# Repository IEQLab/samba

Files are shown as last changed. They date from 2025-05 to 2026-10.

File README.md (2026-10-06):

# SAMBA IEQ Monitoring System

This repository contains the firmware for SAMBA v2, a low-cost indoor environmental quality (IEQ) monitor developed by the [IEQ Lab](https://www.sydney.edu.au/architecture/our-research/research-labs-and-facilities/indoor-environmental-quality-lab.html) at The University of Sydney. SAMBA runs on [ESPHome](https://esphome.io), an open-source firmware framework for ESP32 microcontrollers. The minimum supported version of ESPHome is **2026.9.1**.

### Configuration

ESPHome devices are configured using [YAML](https://yaml.org). This repository is structured so that each sensor or function has its own config file in `config/`, which are imported as [packages](https://esphome.io/components/packages/) by the main [`samba.yaml`](https://github.com/IEQLab/samba/blob/main/samba.yaml).

```
├── samba.yaml              # main config
├── config/
|   ├── adc.yaml            # analog-to-digital converter
|   ├── airspeed.yaml       # anemometers
|   ├── calibration.yaml    # calibration coefficients
|   ├── co2.yaml            # CO2 sensor
|   ├── diagnostics.yaml    # device diagnostics
|   ├── esp32.yaml          # ESP32 board and framework
|   ├── fileserver.yaml     # SD file server for SAMBA Home
|   ├── globals.yaml        # global variables
|   ├── homeassistant.yaml  # Home Assistant API
|   ├── illuminance.yaml    # illuminance sensor
|   ├── influx.yaml         # InfluxDB connection
|   ├── led.yaml            # status LED
|   ├── ota.yaml            # over-the-air updates
|   ├── pm25.yaml           # PM2.5 sensor
|   ├── rtc.yaml            # real-time clock
|   ├── sample.yaml         # sampling loop
|   ├── sd.yaml             # SD card logging
|   ├── spl.yaml            # sound pressure level
|   ├── substitutions.yaml  # secrets and substitutions
|   ├── tags.yaml           # InfluxDB location tags
|   ├── tair.yaml           # air temperature and RH
|   ├── tglobe.yaml         # globe temperature
|   ├── tvoc.yaml           # TVOC and NOx sensor
|   └── wifi.yaml           # wireless networking
├── components/             # custom ESPHome components
|   ├── influxdb/           # InfluxDB v2 HTTP upload
|   ├── sd_file_server/     # read-only HTTP access to the SD log
|   ├── sd_spi_card/        # SPI SD card read/write
|   ├── senseair_i2c/       # K30/K33 CO2 over I2C
|   ├── sgp4x/              # ESPHome's SGP4x, with setup retries
|   └── sound_level_meter/  # I2S audio DSP for SPL
├── firmware/               # compiled binaries for OTA
└── pcb/                    # hardware design files (Altium)
```

The `components/` directory contains six [external components](https://esphome.io/components/external_components.html) that extend ESPHome:

1. `sound_level_meter` — audio DSP for sound pressure level (LAeq, LA90, LA10)
2. `senseair_i2c` — I2C driver for the [K30 CO2 sensor](https://www.co2meter.com/en-au/products/k-30-co2-sensor-module)
3. `influxdb` — HTTP upload to an InfluxDB v2 bucket
4. `sd_spi_card` — FAT32 SD card logging via SPI
5. `sd_file_server` — read-only HTTP service over the SD card log for the SAMBA Home app
6. `sgp4x` — ESPHome's own SGP4x driver, overridden locally so a transaction lost during setup is
   retried instead of disabling VOC and NOx until the next reboot

### Sensors

| Parameter | Sensor | Config | Component |
|:---:|:---:|:---:|:---:|
| Temperature / RH | [Sensirion SHT40](https://sensirion.com/products/catalog/SHT40/) | [tair.yaml](https://github.com/IEQLab/samba/blob/main/config/tair.yaml) | [sht4x](https://esphome.io/components/sensor/sht4x.html) |
| Globe Temperature | [NTC Thermistor](https://www.murata.com/en-us/products/productdetail?partno=NXRT15XH103FA1B040) | [tglobe.yaml](https://github.com/IEQLab/samba/blob/main/config/tglobe.yaml) | [ntc](https://esphome.io/components/sensor/ntc.html) |
| Air Speed | [Thermal Anemometer](https://moderndevice.com/products/wind-sensor) | [airspeed.yaml](https://github.com/IEQLab/samba/blob/main/config/airspeed.yaml) | [ads1115](https://esphome.io/components/sensor/ads1115.html) |
| CO2 | [CO2Meter K30](https://www.co2meter.com/en-au/products/k-30-co2-sensor-module) | [co2.yaml](https://github.com/IEQLab/samba/blob/main/config/co2.yaml) | [senseair_i2c](https://github.com/IEQLab/samba/tree/main/components/senseair_i2c) |
| PM2.5 | [Plantower PMS5003T](https://www.plantower.com/en/products_33/74.html) | [pm25.yaml](https://github.com/IEQLab/samba/blob/main/config/pm25.yaml) | [pmsx003](https://esphome.io/components/sensor/pmsx003.html) |
| VOC / NOx Index | [Sensirion SGP41](https://sensirion.com/products/catalog/SGP41/) | [tvoc.yaml](https://github.com/IEQLab/samba/blob/main/config/tvoc.yaml) | [sgp4x](https://esphome.io/components/sensor/sgp4x.html) |
| Illuminance | [TI OPT3001](https://www.ti.com/product/OPT3001) | [illuminance.yaml](https://github.com/IEQLab/samba/blob/main/config/illuminance.yaml) | [opt3001](https://esphome.io/components/sensor/opt3001.html) |
| Sound Pressure Level | [ICS-43434 Microphone](https://invensense.tdk.com/products/ics-43434/) | [spl.yaml](https://github.com/IEQLab/samba/blob/main/config/spl.yaml) | [sound_level_meter](https://github.com/stas-sl/esphome-sound-level-meter) |

Most sensors are natively supported by ESPHome. The CO2 sensor and sound pressure level measurement use custom external components in `components/`.

### Anemometer Tips

The remote board has two thermal anemometer tips, one on each face. The firmware numbers them the other way round from the [schematic](https://github.com/IEQLab/samba/blob/main/pcb/remote/schematics.pdf), so identify a tip by the face it is on:

| Face | Tip | Schematic sheet | Firmware |
|:----:|:---:|:---:|:---:|
| RJ45 connector | R9 | Airspeed 1 | `as2` (ADS1115 `A1`) |
| Opposite face | R27 | Airspeed 2 | `as1` (ADS1115 `A0`) |

The published `Air Speed` is the larger of the two, or the one still reporting if the other has dropped out.

### Sampling

SAMBA continuously measures environmental parameters, applies quality filters and a moving median, then publishes a summary every **5 minutes**. The routine is:

1. Each sensor measures at its own frequency (see table below).
2. Raw readings pass through [filters](https://esphome.io/components/sensor/index.html#sensor-filters) — NaN rejection, clamping, moving median — and calibration functions.
3. Every 5 minutes, a [cron task](https://esphome.io/components/time/index.html) on the RTC triggers the `sensor_sample` [script](https://esphome.io/guides/automations.html#script-component).
4. The script updates all [template sensors](https://esphome.io/components/sensor/template.html), then publishes to Home Assistant, InfluxDB, and/or the SD card. The LED flashes white with each upload.
5. Publishing is skipped during the first 2 minutes after boot (sensor warm-up).

| Measure | Frequency | Filters |
|:---:|:---:|:---:|
| Air Temperature | 30s | clamp; moving median; linear calibration |
| Relative Humidity | 30s | clamp; moving median; linear calibration |
| Globe Temperature | 23s | clamp; moving median; linear calibration |
| Air Speed | 2.3s | clamp; moving median; exponential calibration with air temperature |
| CO2 | 27s | filter; clamp; moving median; linear calibration; clamp |
| PM2.5 | ~1s | clamp; moving median |
| VOC Index | 30s | moving median |
| NOx Index | 30s | moving median |
| Illuminance | 20s | clamp; moving median; linear calibration; clamp |
| Sound Pressure Level | 125ms | sos (mic EQ, A-weighting); sliding 5min window of 125ms levels, sent each minute: energy average (LAeq), 0.1dB histogram quantiles (LA90, LA10) |

### Data

Published measurements are sent every 5 minutes to one or more of the following backends:

**[Home Assistant](https://www.home-assistant.io)** — An open-source home automation platform. Easy to use but requires additional hardware (e.g. Raspberry Pi) and some configuration to retain raw data beyond 10 days. Best suited for projects that also collect other measurements (e.g. energy, window/door state). Communication uses the native ESPHome [API component](https://esphome.io/components/api.html).

**[InfluxDB](https://www.influxdata.com/products/influxdb-overview/)** — An open-source time series database optimised for IoT. Can be self-hosted or used via InfluxData's cloud service. Requires an active internet connection. Best suited for field deployments of multiple SAMBAs. Communication uses the custom `influxdb` component with building, level, and zone IDs as tags (set over the native API, see [`config/tags.yaml`](https://github.com/IEQLab/samba/blob/main/config/tags.yaml)). See the [InfluxDB key concepts](https://docs.influxdata.com/influxdb/v1/concepts/key_concepts/) for background.

**SD Card** — Local CSV logging via the `sd_spi_card` component. Files are named using the device MAC address and UTC timestamp. No network connection required.

### Status LED

A single RGB LED on the board reports device state. One rule covers the whole scheme:
**colour identifies the subsystem, and pulsing versus solid identifies severity.** A slow
pulse is a warning the device expects to recover from on its own; a steady light means the fault
is sustained. Only the ADS1115 and K30 escalate to a restart, and only after an hour of uptime.
Brightness is deliberately low throughout so a rack of units is not distracting in an occupied
office.

For a bedroom or any space that should stay dark, turn off the *Status LED* switch (native API,
persists across reboots and updates). Every indication below is then suppressed, including the
boot flash, the sample heartbeat and the fault colours; faults are still logged and still
restart the unit as described. *Identify SAMBA* still blinks the LED, since it is only ever
pressed on purpose.

| LED | Meaning | What to do |
|-----|---|---|
| Green, flashing | Booting | Nothing — clears after startup |
| White, brief flash | 5-minute sample taken and uploaded | Nothing — this is the healthy heartbeat |
| Off | Running normally | Nothing |
| Amber, pulsing | Globe temperature / air speed unresponsive ~3 min | Watch — often transient |
| Amber, solid | Same, ~5 min. Restarts once the fault has covered 35% of the last hour (about 25 min continuous) | Check the RJ45 cable to the remote board, then reseat both ends |
| Blue, pulsing | CO2 (K30) failed 3 consecutive reads | Watch — usually self-recovers |
| Blue, solid | CO2 failed 4 or more; restarts once it has failed 67% of the last hour (about 65 min of near-total failure) | Check the K30; a persistent fault is often board-specific rather than the sensor |
| Magenta, pulsing | VOC / NOx (SGP4x) failed 4 consecutive reads | Watch — usually self-recovers |
| Magenta, solid | VOC / NOx failed 6 or more. Never restarts: the sensor keeps retrying itself, and a reboot would discard its month-long baseline | Check the sensor |

The LED is applied from a single 10-second poll of the error counters rather than from each
sensor's error handler, so it survives the sample heartbeat and returns to off within about ten
seconds of the sensor recovering. If two subsystems are in trouble at once, the more severe one
shows, and the ADS1115 wins a tie.

**A lit LED does not mean the device has stopped working.** A failed sensor is reported as
`nan` and left out of the upload, while every other measurement continues to be sampled and
sent. Restarts are rate-limited to at most one per hour precisely so that one dead sensor
cannot take the whole unit off the air.

Every sensor drops out the same way: each stamps the time of its last successful read, and a
measurand goes `nan` once that stamp is more than 5.5 minutes old — one sample interval plus
margin. A single failed read never costs a reading, because the sensors poll far faster than
they are sampled; it takes eleven consecutive failures for temperature, humidity or illuminance,
12 for CO2, 14 for globe temperature and about 140 for air speed. What this does *not* catch is
a sensor that keeps answering with a stuck value.

Amber is the one worth attention in the field: the remote board connects over an RJ45 lead,
and a marginal cable is the most common cause of it.

### Modifying Firmware

Users are free to modify the SAMBA firmware to suit their needs. We recommend familiarity with ESPHome and microcontroller programming before doing so. To get started:

1. Copy `secrets.yaml.example` to [`secrets.yaml`](https://esphome.io/guides/yaml.html#secrets-and-the-secrets-yaml-file) and set your InfluxDB server.
2. Modify the relevant `.yaml` files in `config/`.
3. Compile and upload via USB-C with `esphome run samba.yaml`, or wirelessly with `esphome run samba.yaml --device <IP_ADDRESS>`.

Calibration coefficients are stored as persistent [global variables](https://github.com/IEQLab/samba/blob/main/config/globals.yaml) and exposed as number entities over the native API (`config/calibration.yaml`), so they are set on the device rather than compiled in.

The user is responsible for managing any device running modified firmware.

### OTA Updates

SAMBA devices check for firmware updates every Monday at 04:00 UTC by comparing against [`firmware/manifest_v2.json`](https://github.com/IEQLab/samba/blob/main/firmware/manifest_v2.json). If a new version is available, the update is applied automatically after a random delay of up to 10 minutes to avoid fleet-wide simultaneous downloads. Units still on 1.x read [`firmware/manifest.json`](https://github.com/IEQLab/samba/blob/main/firmware/manifest.json) and never update to 2.x on their own; they move to 2.0 only when the IEQ Lab reflashes them. Automatic updates can be disabled with the *Automatic Updates* switch (see [Deployment](#deployment)).

### Deployment

SAMBA devices are shipped pre-calibrated, with their location tags (building, level, zone) and calibration coefficients already set by the IEQ Lab. Follow these steps to connect a new SAMBA to your network and start sampling:

1. **Power on** the SAMBA. The status LED blinks green while it boots. This firmware has no separate setup colour, so a unit still waiting for a network looks the same as one that is sampling.
2. **Connect to the hotspot.** Using a phone or laptop, join the SAMBA's own open WiFi network — it is named after the device, `samba-xxxxxx`, where `xxxxxx` is the last three bytes of its MAC address — and open the [captive portal](https://esphome.io/components/captive_portal.html) at [http://192.168.4.1](http://192.168.4.1). There is no password on the hotspot.
3. **Enter WiFi credentials.** Select the target 2.4 GHz network from the list and enter the password. The SAMBA will connect and begin sampling automatically. The LED will blink green during the warm-up period and then turn off once it enters the normal sampling routine.

**Switch it on in the room it will monitor.** The VOC sensor's index is relative: it learns a baseline from the air it sees in its first 45 minutes and then holds that baseline for about a month, so the first hour sets the scale every later TVOC reading is reported against. Boot the unit in its final position under normal conditions — not on a bench in another room, and not somewhere unusually clean or unusually solvent-heavy. If a unit's first hour was unrepresentative, power-cycling it within three hours discards the baseline and it learns again from scratch; after three hours only a firmware update clears it. This also means TVOC may step to a new baseline after an automatic update. Nothing else in the unit depends on where it is first switched on.

The location tags, the *InfluxDB Upload* / *SD Card Write* / *Automatic Updates* switches and the calibration coefficients are exposed over the [ESPHome native API](https://esphome.io/components/api.html), so they can be viewed and changed from [Home Assistant](https://www.home-assistant.io/integrations/esphome/) or with the IEQ Lab's `samba` laptop client from [samba_calibration](https://github.com/IEQLab/samba_calibration) (its *Identify SAMBA* button blinks the LED to pick one unit out of a batch). If you need a SAMBA recalibrated or re-tagged, please reach out — see [Project Maintenance](#project-maintenance) below.

The API is [encrypted](https://esphome.io/components/api.html#configuration-variables) with a key that is set on the device by the IEQ Lab during deployment rather than compiled into the firmware, so the published binaries carry no key; until one is set, the device accepts unencrypted connections so it can be provisioned. The same is true of the InfluxDB token and the OTA password (see `config/influx.yaml` and `config/ota.yaml`): each is stored on the device, survives updates, and the device only ever reports a fingerprint of it (*InfluxDB Token*, *OTA Password*) together with the result of its last upload (*InfluxDB Status*). The published firmware has no compiled-in fallbacks: a unit that has not been provisioned does not upload to InfluxDB and takes OTA updates without a password, so provision it before it leaves a network you trust. To upload to your own InfluxDB instead, set `token:` in `config/influx.yaml` in your build; a provisioned token still takes precedence. A unit going into a home gets a fourth credential, a pairing password that turns on a read-only HTTP service over the SD card log for the SAMBA Home app (see `config/fileserver.yaml` and [docs/home-sync.md](docs/home-sync.md)); without one the service is off and the unit behaves exactly as a building unit.

### Project Maintenance

This is an active project to build an open research platform for healthy, high-performance buildings. If you're interested in using SAMBA in your project or contributing to its development, start a [Github discussion](https://github.com/IEQLab/samba/discussions) or email Tom.

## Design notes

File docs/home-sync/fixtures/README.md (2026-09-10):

# Home sync conformance fixtures

These files are the shared test input for everything that reads a SAMBA SD log: `SambaCore` on
iOS, the Android port, and the firmware bench test. The wire contract itself is section 2 of
[../../home-sync.md](../../home-sync.md); this directory is that contract as bytes, so a port is
written against files rather than against someone else's source.

A parser conforms when, for each log file, it produces exactly the rows in `expected/`, and when
it handles every case in `ranges.json`.

## What is here

| File | What it is |
|---|---|
| `F8B3B7C65CDC_260910_0412.txt` | Six clean hours, 72 rows, ends with a newline. The ordinary case. |
| `F8B3B7C65CDC_260910_2347.txt` | 42 rows across UTC midnight, with sensor faults and a hole in the record. |
| `F8B3B7C65CDC_260911_0753.txt` | 11 rows and a twelfth cut off mid-field by a power loss. No trailing newline. |
| `listing.json` | The `GET /sd` body listing those three files, with their real sizes. |
| `expected/<log>.json` | Every row of that log as parsed: `ts` in Unix seconds, `null` for each `nan`. |
| `ranges.json` | Fetch cases: cold, incremental, resumed mid-row, chunked, and `416`. |
| `make_fixtures.py` | Regenerates all of the above. |

The measurements are synthetic. No home unit has shipped yet, so there is no real log to cut
down, and a fabricated file that is honest about being fabricated is better than a hand-typed one
that quietly gets the number formats wrong. Everything a parser can observe — the header block,
the column order, the printf precision of every field, the two spellings of NaN, the line ends,
the file names — is what `config/sample.yaml` and `config/sd.yaml` actually write. The values
themselves come from a rough model of a flat over an afternoon and a night: they move the way a
room moves so that a chart drawn from them looks wrong when the chart is wrong. Replace them with
a real log the first time a unit has run for a day, and keep the same file names and cases.

## The three logs, and what each one is for

**Clean.** Opens with the row quoted in `home-sync.md` section 2, which is also the row
`SambaCore`'s parser test asserts. Timestamps are five minutes apart throughout, and the file
ends with a newline, so a cold fetch leaves no fragment.

**Faults and a hole.** Three things at once, all of which a port gets wrong by default:

- The CO2 sensor is out for five rows: `co2` reads `nan` and must be stored as null, not zero and
  not the previous value. The other twelve measurands in those rows are good and must be kept.
- An ADS1115 fault takes `tg`, `as` and `mrt` together for three rows, since the globe
  thermistor and both anemometers hang off that ADC and MRT is computed from them. One field is
  spelled `-nan`: newlib prints the sign bit, so a calibration lambda that negates a NaN yields
  that spelling on the card. Both spellings are null.
- SD writing was switched off for half an hour, so rows 02:00 to 02:25 do not exist. The record
  has a 35-minute hole in it, listed in `gaps` in the expected JSON. A chart breaks the line
  there; it never interpolates across it, and the missing rows are not an error.

Row timestamps also cross UTC midnight into the next day, which is the case that breaks a parser
that has quietly assumed local time.

**Cut short.** The last line is a partial row with no newline, and it stays that way: the unit
lost power mid-append and the row is never completed. A parser keeps the 11 complete rows, holds
the partial line as the fragment, and stores nothing for it. The bookmark still advances to the
full file size, so the next listing shows an equal size and the file is skipped.

## Using them

The log files are ASCII with LF line ends. Reading them as bytes and splitting on `0x0A` is the
safe route: some HTTP clients and test helpers rewrite line ends, and a splitter that searches
for a `"\n"` *character* misses a CRLF that a helper introduced. Nothing in these fixtures
contains a CR.

`expected/<log>.json` carries, alongside the rows, the counts a test can assert cheaply first:
`bytes`, `rows`, `first_ts`, `last_ts`, the per-column `nulls`, and the `gaps`. The sample field
names are the CSV column names, so `as` is air speed — in the SQLite schema that column is `as_`,
because `as` is a keyword in both Swift and Kotlin.

`ranges.json` describes each fetch as the state before, the request, the response the firmware
gives, and what the store should hold afterwards. `state_before` is a file's row in the `file`
table: `bytes_synced` and `fragment`. The `resume-mid-row` case is the one worth reading twice —
the bookmark sits inside a row and the fragment holds that row's opening bytes, which is exactly
what a fetch interrupted by a dropped WiFi link leaves behind.

## Regenerating

```bash
python3 docs/home-sync/fixtures/make_fixtures.py
```

Deterministic, stdlib only. The generator writes the log text first and then reads every expected
value back out of that text with a second parser, so the JSON cannot drift from the bytes it
describes.

Because both sides of the port are pinned to these bytes, a regeneration that changes a log file
is a change to the wire contract. Review it as one: update section 2 of `home-sync.md` in the
same commit, and expect the conformance tests in `SambaCore` and the Android port to move with
it.

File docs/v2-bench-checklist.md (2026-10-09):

# Bench checklist: SAMBA 2.0.0 release candidate (samba main @ `5a0d102`)

Bench unit F8:B3:B7:C7:C4:18 (locations.csv: wilkinson / 4 / bench). Run `samba` from the
samba_calibration checkout. Plan: `docs/v2-release-plan.md` §9.1–9.3 and §9.5. The candidate
is built from main at or after `9be537c` (no `f_getfree` after mount). It reports build time
2026-10-07 14:58:37: ESPHome only renews that stamp when the config hash changes, and nothing
after that build touched the config. Built 2026-10-09; binaries and `.elf` in `~/samba-rc/2.0.0-rc1-5a0d102`.

## Setup on the bench laptop

```bash
cd <samba>             && git fetch && git switch main && git pull
cd <samba_calibration> && git fetch && git switch main && git pull && uv sync --extra dev
B=~/samba-rc/2.0.0-rc1-5a0d102     # the candidate: .ota.bin, .factory.bin, .elf
C=~/samba-bench                     # calibration_v1.13.factory.bin and the published samba_v1.99.99.bin
(cd $B && md5 -r *.bin | diff - md5.txt) && echo MD5 OK     # Linux: md5sum *.bin | awk '{print $1"  "$2}'
cd <samba_calibration>   # every `uv run samba ...` below runs from here
uv run samba buildings list   # does this laptop hold wilkinson's key, OTA password and token?
```

The candidate was never put on a release: it lives on the bench laptop only, and the commands
below that use `$B/calibration_v1.13.factory.bin` or `$B/samba_v1.99.99.bin` took them from `$C`.
The 2026-09-24 binaries came from the `v2.0.0-bench` draft release, deleted 2026-10-09 once 2.0.0
shipped; copies are in `$C`. Do not rebuild samba for a session: builds are not reproducible, and the
stashed `.elf` files are what decode a crash from these exact binaries.

| File | md5 |
|---|---|
| `samba_v2.0.0.ota.bin` | 8c68a355264c1c35d45a57460c19ae86 |
| `samba_v2.0.0.factory.bin` | ade04b3a14cb0fa660ab4839b6ca9e74 |
| `samba_v1.99.99.bin` (published) | 8d9356725174bbff9655deaa6a2743ca |
| `calibration_v1.13.factory.bin` | see `md5.txt` |

## 0. Before you start

- [ ] **Credentials.** `buildings.csv` records wilkinson's fingerprints (API key a6f02ba9,
      OTA ba978482, token 7c11d363); the home laptop's config.toml holds none of them. If
      `samba buildings list` shows them here, you are set. Otherwise find them (password
      manager: `samba buildings secrets set` / `samba buildings token`) or mint new ones (`samba buildings secrets mint wilkinson`, `samba buildings mint wilkinson`),
      which changes the fingerprints for every wilkinson unit. §9.2 cannot run without them.
- [ ] If the bench unit holds the wilkinson key and you cannot recover it, `samba` cannot reach
      it over the API. Start at §9.2's erase and run §9.1 on the 2.0 build instead, which is
      the build that matters anyway.
- [ ] USB cable and a serial monitor: `uv run samba flash ports`, then keep
      `uv run python -m serial.tools.miniterm /dev/cu.<port> 115200` open. Safe mode has no API,
      so `samba logs` shows nothing there. Close it before any `samba flash serial`.
      A data cable: a charge-only one powers the unit and no port appears.
- [ ] **Opening the port resets the unit** (CP2102N; presetting DTR/RTS does not stop it). Open
      one monitor before a test and leave it open rather than reopening it to look. Never open it
      within 60 s of an OTA boot: the image is only marked valid at `Boot seems successful`, so
      the reset rolls it back (`OTA rollback detected! Rolled back from partition 'app0'`).
- [ ] OTA **from the calibration image** needs the lab OTA password, which config.toml does not
      hold: `export SAMBA_OTA_PASSWORD="$(uv run python -c "import yaml; print(yaml.safe_load(open('firmware/secrets.yaml'))['ota_password'])")"`.
      Without it `samba flash ota` fails with `ESP requests password, but no password given!`.
- [ ] Turn *InfluxDB Upload* off before any token lands if the bench data must stay out of the
      buckets. It persists across reboots and OTA, and the post-token test write honours it.
- [ ] Probably: after every OTA from the calibration image, the unit comes up as an access point
      (`samba-xxxxxx`). The calibration image's WiFi is compiled in, and neither 2.0 nor 1.99.99
      carries networks, so onboard it through the captive portal with a phone.

## §9.1 Safe mode (crashed on 2026.9.0; passes on 2026.9.1)

- [ ] Unit running 2.0 (or main), on WiFi, serial monitor open. Note its IP.
- [ ] `samba ui` → the unit's Device page → *Restart SAMBA (Safe Mode)*.
- [ ] Serial shows `SAFE MODE IS ACTIVE`. Wait over 60 s: **no reboot** means the boot survives.
- [ ] `uv run samba flash ota <IP> --bin $B/samba_v2.0.0.ota.bin --no-verify --require-encryption --building wilkinson`
      (`--no-verify` is required: without it the command stops at the API connect. `--building`
      supplies the key and password no session can name; samba_calibration 67cac74 and later.)
- [ ] **Passes** if the upload runs to completion and the unit comes back in normal mode on the
      pushed build (`samba info`). Safe mode can be told from normal mode without serial: port
      6053 (API) closed, 3232 (OTA) open.
- [ ] A `Guru Meditation Error ... LoadProhibited` at the handshake (`EXCVADDR: 0x00000048`,
      backtrace in `ESPHomeOTAComponent::handle_handshake_`) is the 2026.9.0 bug: the binary was
      built with ESPHome older than 2026.9.1. Save the raw `Backtrace:` line and decode it with
      `xtensa-esp32-elf-addr2line -pfiaC -e <elf> <PC> <addrs...>`.
- [ ] Captive-portal upload as the recovery route is optional; USB always works:
      `uv run samba flash serial --bin $B/samba_v2.0.0.factory.bin`.

## §9.2 Factory-fresh flow

- [ ] `uv run samba flash serial --erase --bin $B/calibration_v1.13.factory.bin`
- [ ] Unit joins the lab WiFi on the calibration image; `uv run samba info <IP>`.
- [ ] `uv run samba flash ota <IP> --bin $B/samba_v2.0.0.ota.bin` with `SAMBA_OTA_PASSWORD` set
      (§0). The unit comes up as an AP, so the command times out waiting for it: expected.
- [ ] Onboard WiFi through the captive portal if it comes up as an AP.
- [ ] `uv run samba info <IP> --entities`: production 2.0.0, API not keyed, *InfluxDB Token*
      `unset`, *InfluxDB Status* `unknown` (it reads `no token` only once a sample has tried to
      upload), *OTA Password* `unset`, `Anemometer 1 [K]` −6.559 and `Anemometer 2 [K]` −6.809
      (the fleet defaults), *Air Speed Model* `exp2`.
- [ ] `uv run samba deploy --mac F8:B3:B7:C7:C4:18 --dry-run`, then without `--dry-run`: key,
      OTA password, tags, token, each readback-verified, and C4:18's coefficients if it has a
      processed row in `data/v2`; without one it writes credentials and tags only until R33 lands.
      Note which happened. (It says "nothing to deploy" if this laptop holds no wilkinson credentials.)
- [ ] Coefficient persistence by hand: on the Device page, Set `Air temperature slope [m1]`
      to 1.600 and `Anemometer 1 [K]` to −6.000; both should read back. Note the values they
      replaced, to restore afterwards.
- [ ] `uv run samba home password <IP>` with the **existing** pairing password (Desktop label).
- [ ] *InfluxDB Status* reads `HTTP 204` within seconds of the token landing.
- [ ] Power-cycle, then `uv run samba status --live --mac F8:B3:B7:C7:C4:18`: same fingerprints,
      encrypted, tags intact, calibration "partly custom" with the two hand-set values kept.
- [ ] One authenticated OTA: `uv run samba flash ota <IP> --bin $B/samba_v2.0.0.ota.bin`
      (uses the building password and key).

## §9.3 Reflash from 1.x

- [ ] `uv run samba flash serial --erase --bin $B/calibration_v1.13.factory.bin`
- [ ] `uv run samba flash ota <IP> --bin $B/samba_v1.99.99.bin`; onboard WiFi if needed.
- [ ] `uv run samba tag <IP> --building wilkinson --level 4 --zone bench`, plus one non-anemometer
      coefficient by hand on the Device page (e.g. Ta slope), and note it.
- [ ] The Device page shows `Air speed 1 [a]…[d1]` (the power-law line) and the unit reads
      "firmware defaults" apart from the hand-set Ta slope. (The line's "takes no coefficients"
      refusal is covered by the test suite; with no processed/ there is nothing to refuse here.)
- [ ] `uv run samba flash ota <IP> --bin $B/samba_v2.0.0.ota.bin`
- [ ] Check: tags survive; the hand-set Ta coefficient survives; the anemometers show the
      default `K` (−6.559 / −6.809) and `Air Speed Model` reads `exp2`; the unit is unkeyed, *InfluxDB Token* `unset`, *OTA Password* `unset`.
- [ ] Re-provision (`samba deploy`) and the same pairing password.

## §9.5 24 h heap watch

- [x] **Method:** a heap variant, `samba.yaml` plus ESPHome `debug:` sensors (*Heap Free*,
      *Heap Largest Block*, *Heap Min Free*, 60 s) as API entities only, polled from a laptop every
      5 min. Production 2.0 has no heap sensors (roadmap R45), so this is not the candidate binary.
- [x] Run 24 h with uploads on, so the TLS upload and the 12 h firmware check both run. Run on the
      three production units instead of C4:18, and cut to ~19.6 h (record below).
- [x] **Passes** if there is no reboot, the lowest free heap stays at or above the 6 KB floor seen
      before `spl-class2-prep` (plan §13; the crash-looping build reached 0.4 KB), and the largest free block does not trend down across the day.

## Record

Crash confirmed or refuted (with PC and EXCVADDR); any step that deviated; the fingerprints after
the power cycle; the heap minimum and largest-block minimum over 24 h. On a pass, `/bump 2.0.0 --tag --no-compile`
in the build directory the candidate came from, so the released binary is the benched one; builds are not reproducible.

### Release candidate, 2026-10-09, samba `5a0d102`, ESPHome 2026.9.1

*§9.2 and §9.3 not run yet.* Flashed OTA, encrypted, to chamber2 (6A:78) and researchers_area
(C8:70) on 2026-10-09, and chamber1 (CC:84) once it was plugged back in (someone had unplugged it
after the heap watch ended; it answered every poll to 11:40 on 10-08).

**§9.2: passed** on F8:B3:B7:C7:C4:18, 2026-10-09. `--erase` + calibration 1.13, OTA to the
candidate with the lab password, captive portal. Fresh state as expected: production 2.0.0, API
open and unkeyed, token / OTA password `unset`, file server off, `K` −6.559 / −6.809, `exp2`, Ta
slope 1.034, 48 entities. Deploy 6/6 with readback (no processed row, so credentials and tags only:
key a6f02ba9, OTA ba978482, token 7c11d363, wilkinson / 4 / bench). Hand-set Ta slope 1.600 and
`Anemometer 1 [K]` −6.000 read back. Pairing password reapplied from `home_pairing.csv`
(56afa0b7). *InfluxDB Status* `HTTP 204` after the token (checked for the first time; uploads were
on, as the erase leaves them). After a power cycle: encrypted, all four fingerprints, tags and both
hand-set values unchanged; `status --live` reads tags and credentials `match`, calibration "partly
custom". Authenticated OTA with `--require-encryption` succeeded (same build stamp, same bytes).

**§9.3: passed**, from the **published** v1.99.99 this time (md5 8d9356…, ESPHome 2026.8.1).
`--erase` + calibration 1.13, OTA to v1.99.99 with the lab password, captive portal. On 1.99.99:
plaintext API, `Air speed 1/2 [a]…[d1]`, the RH pair and *Factory Restore SAMBA* present (50
entities). `samba tag` wilkinson / 4 / bench and Ta slope 1.600 by API, both read back. Deviation:
`status --live` shows calibration `-`, not "firmware defaults", for 1.99.99 (the client no longer
reads the power-law line, R26) and flags it "needs the 2.0 flash" (R27). The OTA to the candidate
was first refused, `Authentication invalid`: once the tags name wilkinson the client offers the
building's password, which 1.99.99 does not hold. Passing the config's fleet `ota_password`
(1.99.99's compiled-in one) with `--password` worked, in plaintext as 1.99.99 offers no encryption.
On 2.0: tags and the Ta slope kept, `K` −6.559 / −6.809, `exp2`, unkeyed, token / OTA password
`unset`, file server off, power-law, RH and factory-restore entities gone (48). `samba deploy` 6/6
with readback and the pairing password (56afa0b7) restored it; `status --live` then reads
encrypted, `HTTP 204`, tags and credentials `match`. Left at the fleet-default Ta slope (1.034)
with *InfluxDB Upload* off, as before the erase.

**§9.5 release candidate gates complete:** 9.2 and 9.3 passed on `5a0d102`, 9.5's heap watch
passed on its heap variant. Released as v2.0.0 (`f1dda8a`) with `--no-compile`: `firmware/samba_v2.0.0.bin`
is this build (md5 8c68a355…). Bump step 5 on C4:18 with that file: an encrypted OTA, then *Restart
SAMBA (Safe Mode)*, API closed and OTA open for over 90 s, an encrypted `--no-verify --building
wilkinson` OTA into safe mode, and back in normal mode on 2.0.0 within 5 s, settings unchanged.

### 2026-10-07/08, §9.5 heap watch: heap variant of samba 81bdf65, ESPHome 2026.9.1

**Passed, on a shortened run.** Heap variant (`samba_heap.yaml`, built 2026-10-07 15:44:18, md5
`7a69caae4c5782a3c052f8f17c6fc728`) flashed OTA, encrypted, to the three production units in
place at wilkinson / 4, uploads on: chamber1 (CC:84) 15:47, chamber2 (6A:78) 15:58,
researchers_area (C8:70) 16:05 AEDT. Polled every 5 min to 2026-10-08 11:40 AEDT, ~19.6 h from
the last flash, and stopped there because the logging laptop had to leave the network, not
because of a fault. That is not the full 24 h, and it caught one 12 h firmware check, not two.

| Unit | Polls | Uptime at end | Lowest free | *Heap Min Free* | Largest block |
|---|---|---|---|---|---|
| chamber1 | 239 | 71490 s | 123948 B | 77124 B | 45056 B every poll |
| chamber2 | 237 | 70796 s | 122912 B | 76944 B | 45056 B (81920 B before the first upload) |
| researchers_area | 236 | 70630 s | 122844 B | 76844 B | 45056 B every poll |

No reboot (uptime never fell), no failed poll. *Heap Min Free* sits ~13x above the 6 KB floor,
against 0.4 KB on the crash-looping `spl-class2-prep` build. It stepped down ~1.2 KB once per unit
about 12 h after boot (the TLS firmware check, which returns 404 until 2.0.0 is released) and not
otherwise. The largest block was flat all night, so no fragmentation trend. The three units still
run the variant, reporting 2.0.0, and take the tagged build with the R35 reflash.

### 2026-09-24, `v2.0.0-bench` draft binaries (samba 26cb36d; draft deleted, copies in `~/samba-bench`), ESPHome 2026.9.0

§9.1 and §9.2 ran on **F8:B3:B7:C7:D0:6C** (tunnel channel 5, just calibrated), not the bench
unit, which was away as a home test unit. It will be deployed at wilkinson / 4 / chamber1.
§9.3 ran on F8:B3:B7:C7:C4:18, re-tagged wilkinson / 4 / researchers_area. *InfluxDB Upload*
was off on both throughout, so no bench data reached the buckets.

**§9.1: confirmed.** The safe-mode boot survived over 60 s. `samba flash ota --no-verify` then
crashed it at the handshake and it rebooted into normal 2.0.0:

```
Guru Meditation Error: Core  1 panic'ed (LoadProhibited). Exception was unhandled.
PC      : 0x400eba65  EXCCAUSE: 0x0000001c  EXCVADDR: 0x00000048
Backtrace: 0x400eba62:0x3ffb68d0 0x400ebb98:0x3ffb6920 0x400ddca1:0x3ffb6940
ELF file SHA256: b9bdcb9f1
```

```
0x400eba62: esphome::noise::NoiseContext::has_psk() const at esphome/components/noise/noise.h:32
 (inlined by) esphome::ESPHomeOTAComponent::handle_handshake_() at esphome/components/esphome/ota/ota_esphome.cpp:310
0x400ebb98: esphome::ESPHomeOTAComponent::loop() at esphome/components/esphome/ota/ota_esphome.cpp:178
0x400ddca1: esphome::loop_task(void*) at esphome/components/esp32/core.cpp:28
```

The desk reading holds: a null context dereferenced in `handle_handshake_`. EXCVADDR is 0x48,
not 0x4c, which is only the offset of the field read. The upstream null guard goes ahead. The
client's automatic retry then reached the rebooted normal firmware, which asked for the
building password it had not been given; that is the retry, not safe mode.

**§9.2: passed, three deviations.**
- The calibration image refused the OTA without its lab password (now in §0).
- *InfluxDB Status* read `unknown`, not `no token`, before the first sample, and `HTTP 204`
  was not checked because uploads were off on purpose.
- `samba home password` was skipped: a building unit has no pairing password.

Deploy wrote 6/6 with readback: API key a6f02ba9, OTA ba978482, token 7c11d363, tags.
After a hard reset the unit was encrypted with the same three fingerprints, the tags, both
hand-set values (Ta slope 1.600, Anemometer 1 [B] 9.000; since restored to 1.506 and 9.671),
and uploads still off. The authenticated OTA ran encrypted with the building password. At the
first sample every measurand reported: Ta 24.8 °C, Tg 24.5 °C, RH 52 %, CO2 1047 ppm, PM2.5
3 µg/m³, 168 lx, LAeq 35.0 dBA, air speed 0.18 m/s on the placeholders. The SGP4x failed every
poll that boot (TVOC and NOx `nan`, the dropout working as designed); after a power cycle it
read TVOC 76 ppb, NOx 1. Bursts of 2 s-cadence I2C timeouts (the ADS1115) appeared in the
first ~40 s of a boot, stopped, and did not cost globe temperature or air speed. Before the
remote was reseated they ran continuously.

**§9.3: passed, on a different starting build.** C4:18 ran a `main` build from 2026-09-20 that
reports 1.99.99 but already carries provisioning, not the published v1.99.99 binary. So the step
tested more of the upgrade and less of the field path. With the wilkinson credentials deployed
on 1.99.99 and Ta slope set to 1.600, `samba flash ota --require-encryption` to 2.0.0 kept:
encryption with key a6f02ba9, OTA ba978482, token 7c11d363, file server 56afa0b7, tags, the
Ta slope, uploads off. `Air speed [a]…[d1]`, the RH pair and *Factory Restore SAMBA* were gone
and `Anemometer [A]…[k]` sat at the placeholders (54 → 51 entities). Ta slope restored to 1.506.
**The published-v1.99.99 path (unkeyed and tokenless after the upgrade) is still untested**; run
§9.3 as written on the release candidate.

Also seen: `manifest_v2.json` returns 404 until the first 2.x `/bump`, so a 2.0 unit logs an
update-check error at boot and every 12 h and does not update itself. Both units stay on 2.0.0.

### 2026-09-30, main + `min_version: 2026.9.1` (build 2026-09-30 14:25:32), ESPHome 2026.9.1

**§9.1: passed.** On F8:B3:B7:C7:C4:18 (wilkinson / 4 / bench, uploads off), over WiFi only, no
serial monitor. `samba flash ota --require-encryption` from 2.0.0 on 2026.9.0 verified encrypted.
*Restart SAMBA (Safe Mode)* pressed over the API; for 90 s port 6053 stayed closed and 3232
open, so the unit was in safe mode and stayed up. Pushed the same `.ota.bin` with `push_ota`
directly (`samba flash ota --no-verify` has no API session, so no building key, and refuses
`--require-encryption`), wilkinson key, encryption required: `Encrypted connection established`,
`OTA successful`. The unit came back on 6053 and `samba info` read esphome 2026.9.1, the new
build, key a6f02ba9, OTA ba978482, token 7c11d363, tags and uploads unchanged. The encrypted
session in safe mode is the proof the key came from NVS: there is no API server to borrow it
from. Not tested: a plaintext client in safe mode, which by the code is not asked for a password.
Repeated the same day with the CLI once it gained `--building` (samba_calibration 67cac74):
`samba flash ota --no-verify --require-encryption --building wilkinson` in safe mode, encrypted,
unit back on the new build.

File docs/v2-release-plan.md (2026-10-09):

# SAMBA firmware 2.0 — release plan

*Drafted 2026-09-23 against main at 4e47cdc (version string 1.99.99, ESPHome 2026.9.0) and
samba_calibration at adb1b0f. Ten units are in the field on the released v1.99.99. The 2.0 line
is for the 100+ units to come.*

2.0 is a deliberate compatibility break, delivered through a second OTA manifest so the field
units never see it. It bundles three things: the anemometer model changes from a power law to
the level-5 fleet model of §4; credential provisioning ships without compiled-in fallbacks; and everything kept only
for 1.x units or old clients goes. The two lab sessions of §8 are done, and the fleet-median
defaults are committed (§4.2).

*Status 2026-10-07:* §11 steps 1 to 5 are done: the defaults are the 15-unit fleet medians of
2026-10-05 (`630cb24`) and no `TODO(v2)` remains. What remains is the release candidate (§9.5),
built from main at or after `9be537c`, the release and the recall. §11 marks each step.

## 1. Decisions taken

| Question | Decision |
|---|---|
| The 1.x line | Bug fixes only, from a branch off `v1.99.99`; then the ten units are recalled, recalibrated and flashed to 2.0, and the line is retired |
| Scope of the break | The air speed model (§4), the manifest split, credential provisioning without fallbacks, and the 1.x shims listed in §6 |
| Uncalibrated 2.0 unit | Reports air speed from compiled-in fleet-median defaults; the client already tells default from bespoke by value |
| Compiled-in InfluxDB token and OTA password | Dropped. Captive portal and USB remain the recovery paths. No `provisioning:` window |
| The live token and password inside the public v1.99.99 binary | Known exposure, accepted until the ten units are recalled; rotated then |
| `Factory Restore SAMBA` over the API | Removed. A wipe is a USB or lab operation |
| Captive-portal firmware upload | Cannot be closed by config (§5.3); tracked, not a 2.0 blocker |
| Safe-mode crash on main | A release gate, tested on the bench unit before anything ships from main |

## 2. The fork mechanism

The update component fetches `source:` every 12 h, compares the manifest `version` with
`ESPHOME_PROJECT_VERSION`, and installs whenever they differ. `source:` is compiled in and nothing
at run time can change it. So:

- `config/ota.yaml` on the 2.x line: `source: https://github.com/IEQLab/samba/raw/main/firmware/manifest_v2.json`, a literal.
- `firmware/manifest.json` and `firmware/samba_v1.*.bin` stay where they are, unchanged in name,
  read by the 1.x units. `firmware/manifest_v2.json` and `firmware/samba_v2.*.bin` join them.
- A 1.x unit reaches 2.0 only by hand, `samba flash ota` from the lab, after recalibration.

Because a lower manifest version also installs, `manifest.json` must never point at a 2.x
binary. That is the accident `/bump` has to make impossible (§7).

## 3. The 1.x line

Main cannot serve it: every commit after the tag also carries provisioning and 2026.9.0, and
after this plan main drops the compiled-in fallbacks that 1.99.99 units rely on.

- Branch `release/1.x` from `v1.99.99`. Cherry-pick the dropout and watchdog fixes only when a
  fix is actually needed in the field; do not pre-emptively cut a release.
- Versions 1.99.100 and up, built with the ESPHome the tag pins (`min_version: 2026.8.1`), not the
  laptop's current one; a 1.x fix must not also move the toolchain.
- `/bump` as written commits the binary and manifest on the current branch and pushes it, and main
  takes PRs only, so on `release/1.x` the artefacts would land where no unit reads them. The
  procedure is two-branch: bump, build and tag on `release/1.x`; copy `samba_v1.99.1NN.bin` and the
  rewritten `manifest.json` into main's `firmware/` through a worktree and a PR; verify the md5 on
  main before the PR merges. `/bump` refuses to run on a 1.x version until it does this itself (§7).
- The line closes when the last field unit is on 2.0.

## 4. Anemometer calibration in 2.0

*Rewritten 2026-09-25 after the §8 sessions. King's law, the model this section first proposed, is
removed: it is undefined above about 33 °C once k is free, and no unit ever held its coefficients.
The model study and its numbers are in samba_calibration `docs/calibration.md`.*

### 4.1 The model

Per anemometer, with V the median filtered anemometer voltage (volts) and Ta the calibrated air
temperature (22 °C when Ta is NaN, as today):

```
v = exp(K + C1·V + G·(Ta − 22))        clamped to [0.02, 1.0] m/s
```

- `C1` and `G` are **fleet constants**, compiled in as the substitutions `airspeed_c1` (2.9487 V⁻¹)
  and `airspeed_g` (0.2745 °C⁻¹). They are fitted by samba_calibration's `analysis/airspeed_fleet.R`
  and change only with a flash.
- `K` is the **one per-tip coefficient**, measured at level 5 of a calibration run.
- The model has an id, `airspeed_model: "exp2"` (`exp1`, 3.0043 and 0.2321, was fitted before the
  Ta reference was corrected for the tunnel channel's warmer air), published as the `Air Speed Model` text sensor.
  `samba deploy` refuses a `K` fitted under a different id, so refitting the constants means a new
  id here and in the client together.

### 4.2 Entities and globals

| Entity name | id | global | default | range | step |
|---|---|---|---|---|---|
| Anemometer 1 [K] | `cal_as1_k` | `calibration_as1_k` | −6.559 | −12–0 | 0.0001 |
| Anemometer 2 [K] | `cal_as2_k` | `calibration_as2_k` | −6.809 | −12–0 | 0.0001 |
| Air Speed Model (text sensor) | `cal_airspeed_model` | — | `exp2` | — | — |

- `double`, `restore_value: yes`, template numbers with the 60 s update interval, saved through
  `cal_save`, exactly as the existing coefficients.
- New ids on purpose: NVS keys are hashed from the global id, so no power-law or King's-law blob is
  ever read as a `K`. The old entities and globals are removed outright.
- The default is the fleet median of the 14 units that pass exp2 (2026-10-05, roadmap R32),
  replacing the September batch's −6.095 / −6.388. It changes here and in the client's
  `mapping.py` together.
- Units agree: the `as*` columns of `raw/thermal.csv` are volts, the same quantity as the lambda's `x`.

### 4.3 The lambda

```cpp
float ta = id(samba_temperature).state;
if (std::isnan(ta))
  ta = 22.0f;
const float k = id(calibration_as1_k);
if (std::isnan(k))
  return NAN;
const float v = expf(k + ${airspeed_c1}f * x + ${airspeed_g}f * (ta - 22.0f));
return std::min(std::max(v, 0.02f), 1.0f);
```

`x` is at most 5 V, so the exponent stays under about 9 and cannot overflow. `samba_airspeed` takes
`max(as_1, as_2)`; `std::max` is asymmetric with NaN, so it gets explicit `isnan` handling: both
NaN → NaN, one NaN → the other. `tglobe.yaml` already guards a NaN air speed.

## 5. Credentials in 2.0

### 5.1 What stays

`encryption: {}` with the key provisioned over the native API (one image cannot carry per-building
keys); the `influx_set_token`, `ota_set_password` and `fileserver_set_password` actions, their
FNV-1 fingerprint sensors and `global_preferences->sync()` scripts; NVS persistence; the
captive portal as the WiFi onboarding path; `samba flash serial` with the calibration image, then
`samba flash ota`, as the USB route.

### 5.2 What goes

- The compiled-in InfluxDB token: samba's config sets `token: ""`, so "no token" is reported
  until one is provisioned. The component keeps its optional `token:` and the `compiled-in`
  status branch (b942cdf) for open-source builds that upload to their own InfluxDB; a
  provisioned token still takes precedence. The published binaries carry none.
- The compiled-in OTA password: `password: ""` stays in the YAML so `set_auth_password`
  compiles; the "clear reverts to compiled" branch of `ota_set_password` becomes "clear leaves it
  empty".
- The unused wifi, hotspot and enterprise substitutions, the commented `networks` / `manual_ip`
  block in `wifi.yaml`, and their keys in `secrets.yaml.example`.
- `Factory Restore SAMBA`.

Consequence to document: a 2.0 unit that loses NVS loses its API key too. It comes back with a
plaintext API, no token and no OTA password, so until it is redeployed over the LAN it does not
upload, and anyone on its LAN can key it, set its OTA password and flash it. The SD card keeps
logging. This is the same state a factory-fresh unit is in, and the same state every 1.99.99 unit
is in today (§12).

Safe mode is a recovery path again from ESPHome 2026.9.1 (§9.1). On 2026.9.0 the OTA component
dereferenced the API server, which safe mode never constructs, and crashed at every handshake.
esphome#19349 guards it and loads the provisioned API key from NVS instead, so a keyed unit in
safe mode takes an OTA encrypted under its building key. The OTA password is still not applied
there (`on_boot` never runs), so a client that declines encryption is not asked for one.

### 5.3 The captive-portal upload

In ESPHome 2026.9 `captive_portal` auto-loads `ota.web_server`; the upload form is part of the
portal and no option removes it. It is only reachable when WiFi has failed and the access point is
up. Two ways to close it, neither in 2.0: an upstream option on `captive_portal` to skip the OTA
platform (a small PR, the cleanest), or WiFi onboarding by another route so the portal is not
needed. Tracked as a follow-up.

## 6. 1.x shims and dead code removed

| Item | Where | Cost of removal |
|---|---|---|
| RH slope and offset entities | `calibration.yaml`, `globals.yaml` | none: never applied; one client mapping edit |
| `disabled_by_default` on the 18 numbers | `calibration.yaml` | none |
| The `on_client_connected` coefficient dump | `homeassistant.yaml:13-46` | none; the client reads the entities |
| `home_assistant_domain` in the manifest | `/bump` | none |
| `senseair_i2c.cpp` "keeping for compatibility" method | `components/senseair_i2c` | none if no caller; `samba_calibration/firmware/components/` is a verbatim copy and must be refreshed in the same change |
| README lines on editing lambdas, "no web interface", the archived samba_app | `README.md` | docs only |
| CLAUDE.md on Home Assistant-editable coefficients and the 1.x fallback rollout | `CLAUDE.md` | docs only |

Kept on purpose: the 22 °C fallback when Ta is NaN (physics, not compatibility), the `ap: {}`
fallback access point (onboarding), and the Home Assistant API name, which the client matches on.

## 7. `/bump` and CI

- The manifest is chosen from the version's major number: `manifest.json` for 1.x,
  `manifest_v2.json` for 2.x. Refuse a mismatch. The fleet warning at the top of the skill names
  both manifests and which units read each.
- On a 1.x version the skill either performs the two-branch procedure of §3 or refuses; it never
  commits 1.x artefacts to `release/1.x` alone.
- After the build, grep the binary for the manifest URL and refuse if it is not the one the major
  number implies.
- 1.x artefacts land on main's `firmware/` even when built on `release/1.x`.
- The bench check stays: `samba flash ota`, `samba info`, and now the safe-mode gate of §9.1 on
  the release candidate.
- samba has no CI today. Adding `esphome config` on every push is a scoped task in step 2 of
  §11, not an assumption.
- The version string on main moves to 2.0.0 with the first 2.0 commit, so main's binaries and
  logs stop reading 1.99.99.

## 8. What the coefficient values wait on

*Done 2026-09-25.* The in-channel probe sweep and the confirmation session ran, and the model
study that followed them replaced King's law with the level-5 fleet model (§4). The model, the
exclusions, the gate and the numbers are in samba_calibration `docs/calibration.md`.

## 9. Release gates

1. **Safe mode on the bench unit.** *Fixed upstream in ESPHome 2026.9.1 (esphome#19349) and
   passed on hardware 2026-09-30* on F8:B3:B7:C7:C4:18: normal-mode OTA to the 2026.9.1 build,
   *Restart SAMBA (Safe Mode)*, API port closed and OTA port open for over 90 s, then an OTA
   with encryption required completed (`Encrypted connection established`) and the unit came
   back in normal mode on the new build with key, token, OTA password and tags unchanged.
   `min_version` is 2026.9.1 so no build can regress it.
   *First run, 2026-09-24, ESPHome 2026.9.0* (`docs/v2-bench-checklist.md`, on
   F8:B3:B7:C7:D0:6C): the safe-mode boot survived over
   60 s, and `samba flash ota` crashed it at the handshake with `LoadProhibited`, `EXCVADDR
   0x00000048` (the field offset; the desk reading said 0x4c), in `NoiseContext::has_psk()`
   inlined into `handle_handshake_` (`ota_esphome.cpp:310`). It rebooted into normal firmware.
   *Desk result, 2026-09-23:* the boot survives and the OTA
   crashes. `global_api_server` is null in safe mode (it is set only in the `APIServer`
   constructor, emitted after the early return), and `ota_esphome.cpp:34-36`
   `noise_context_()` dereferences it with no null check. It is reached from `dump_config`,
   which compiles to nothing at `logger: level: INFO`, and from `handle_handshake_` (:310) on
   every client that offers the extended protocol, which `espota2.py` always does. The boot
   counter is already cleared by then, so the crash reboots into normal firmware. The bench
   run is therefore a confirmation. Expect `LoadProhibited`, `EXCVADDR 0x0000004c`, PC in
   `ESPHomeOTAComponent::handle_handshake_`. The fix is upstream: a null guard in
   `noise_context_()` returning a keyless context, so safe mode falls back to the password
   path. (Upstream went further: the context falls back to the key saved in NVS.)
   Original procedure: on F8:B3:B7:C7:C4:18 running a main build, press
   `Restart SAMBA (Safe Mode)`, wait past the point where `dump_config` runs (a minute), then push
   a `samba flash ota` while it is in safe mode and watch the upload complete and the unit boot
   normally. The reading of `main.cpp` says `APIServer` is constructed after the safe-mode return
   while `ota_esphome` dereferences it in `dump_config` and in the OTA handshake, so either the
   unit crash-loops at boot or the upload crashes it. Whether the boot survives depends on when
   `dump_config` runs, which only hardware tells. If it reproduces: fix or report upstream before
   any release from main; the `/bump` half-wiring gate does not catch it. Recovery from a failed
   test is a USB reflash.
2. **Factory-fresh bench flow** on the bench unit, starting from `samba flash serial --erase`:
   nothing in NVS survives a flash without `--erase`, and the bench unit already holds every
   credential, so without it this tests nothing. Then calibration image → `samba flash ota` to 2.0
   → key → InfluxDB token → OTA password → the file-server pairing password the unit already had
   (the label on the Desktop; never a new one) → coefficients → tags, every step readback-verified
   by `samba deploy`, then a power cycle and a second `samba status --live` showing the same
   fingerprints.
3. **Reflash-from-1.x flow** on the same unit: `--erase`, flash v1.99.99, provision tags (the only
   thing 1.99.99 can take over the API), then `samba flash ota` to 2.0. Confirm the tags and the
   non-anemometer coefficients survive, the anemometers report the defaults, and the unit is
   unkeyed and tokenless until provisioned; re-provision the same pairing password.
4. `esphome config` clean and the calibration repo's suite green; samba's new CI green.
5. The release candidate: the `K` default confirmed from the next batch's fleet median and
   committed on both sides (no `TODO(v2)`; *done 2026-10-05*, `630cb24`), then gates 2 and 3 re-run on it, since the air speed
   model, defaults and ranges changed after the 2026-09-24 pass. Gate 3 runs from the
   **published** v1.99.99 binary this time; the first pass started from a main build that already
   carried provisioning. The 24 h free-heap and largest-free-block watch of §13 runs on the same
   build.

## 10. Client changes (samba_calibration)

- `deploy/mapping.py`: `COEFFICIENTS`, `FIRMWARE_DEFAULTS`, `CSV_COEFFICIENTS` and
  `CALIBRATED_COEFFICIENTS` per firmware line, chosen by entity presence alone (a
  `project_version` cross-check only adds a disagreement state). Not a new flavour. Drop the RH
  pair and the below-1.9 aliases. The 2.x line's air speed group is `K` per tip (§4).
- `api/client.py`: `capabilities.coefficients` per line rather than all eighteen names.
- `deploy/updates.py`: the coefficient group per line. A v1.99.99 unit takes tags only: it has no
  token, password or key actions and no `encryption:`, so credentials cannot be pushed to it and no
  power-law rows will ever be written again. `has_group` keys on the new names.
- `data/schemas.py`: the air speed processed table is `as{1,2}_k, _samples, _rmse, _rel_max` and
  `airspeed_model`. `processed/` does not exist yet, so nothing migrates.
- `models/`: `K` per tip from level 5 of the included runs, scored on levels 1–7 against RMSE ≤ 0.20
  and every point within max(25 %, 0.05 m/s); `analysis/models.R` first, port second, goldens third.
- `deploy/live.py`: default detection unchanged in mechanism, keyed by line.
- `docs/deployment.md`: the "credential-provisioning branch" paragraph is stale now; the
  compiled-in-fallback warnings go when 1.x closes.
- Tests: `test_live.py` reads defaults from the sibling checkout and will break on the first
  firmware commit; pin it to the line.

## 11. Sequence

1. *Done 2026-09-24.* Bench: the safe-mode gate (§9.1). Half a day, and it decides whether 2.0
   starts from main.
2. *Done (PR #24, then 60ab521 for the `exp1` model).* Firmware branch `v2`: manifest split, version 2.0.0, credential removals, shim removals
   (with the `senseair_i2c` refresh into the calibration repo), the air speed entities with
   provisional defaults, lambda. `esphome config` clean. `/bump` changes and the new CI.
3. *Done* (samba_calibration `docs/roadmap.md` R26–R28). Client: mapping, capabilities, updates, schema, live, tests. Suite green against the `v2`
   checkout; the calibration image is unaffected and stays as the unconditional check it is.
4. *Done 2026-09-24.* Bench: the factory-fresh and reflash-from-1.x flows (§9.2–9.3) on the provisional build, to
   shake out the flows themselves.
5. *Done 2026-10-05* (`630cb24`, roadmap R30/R32). Lab: the probe
   sweep and the confirmation session (§8). Model, port, goldens, defaults, and
   the ranges if the fit needs them.
6. *Done 2026-10-09* (`f1dda8a`, tag `v2.0.0`, md5 8c68a355…). Bench again on the release candidate (§9.5), then release 2.0.0 through `/bump` to
   `manifest_v2.json`. Tag. The first batch is calibrated and deployed on 2.0.
7. Recall the ten field units over the following batches; rotate the InfluxDB token and the OTA
   password when the last one is in; retire `release/1.x` and `manifest.json`.

## 12. Known exposures during the transition

- The public v1.99.99 binary holds the live InfluxDB token and OTA password until the rotation
  in step 7.
- A 1.99.99 unit is plaintext-API: anyone on its LAN can key it and then flash it without the
  password. A 2.0 unit that loses NVS is in the same state until redeployed.
- The captive-portal upload (§5.3) is unauthenticated in every version. Safe mode is an OTA path
  from 2026.9.1 (§9.1): encrypted under the building key when the client offers it, but with no
  password, so a client that declines encryption can flash a unit in safe mode.

## 13. Open items not decided here

- *Decided 2026-09-24:* `spl-class2-prep` rides along in 2.0. `la_eq` becomes a true energy
  average (it was L50) and LA90/LA10 move to 125ms blocks, so all three shift at the 2.0 boundary;
  2.0 demarcates it in the data. As first merged it crash-looped a bench unit at boot: the two
  2400-value `quantile` filters held 19.2KB of heap and copied a 9.6KB window on every output,
  and the TLS firmware check ~10s after WiFi then ran out (lowest free heap 0.4KB, against
  6-16KB before). `sound_level_meter` now computes all three itself (`type: stats`): 125ms
  levels as uint16 deci-dB in one 4.8KB ring plus a 2.8KB 0.1dB histogram, allocated once in
  setup, with nothing allocated per block or per output. The §9.5 bench run still watches free
  heap and largest free block over 24h.
- The upstream `captive_portal` option, or a different onboarding route.
- Whether the 2.0 firmware exposes anything for the home app that the manifest split changes
  (`project_version` in the TXT record now reads 2.x).

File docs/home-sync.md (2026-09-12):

# SAMBA Home Sync — implementation plan (Option 2)

*Drafted 2026-09-10 against samba firmware 1.99.99, ESPHome 2026.8.1 on ESP-IDF, ESP32-WROOM-32E
(no PSRAM). Target app: iOS 17+, Swift 6, with an Android pathway.*

A read-only file service on the SAMBA firmware, gated behind a per-unit password, and an iPhone
app that discovers the unit on the home WiFi, syncs the SD log incrementally, and charts it
locally. No Home Assistant, no InfluxDB, no cloud.

## 1. What gets built, and what deliberately does not

| Concern | Decision |
|---|---|
| Live reading | The last row of the SD log. Template sensors only change in the 5-minute sample script, so the newest CSV row *is* the live value. No native API client and no stock `web_server` on the phone. |
| History | Range requests on the log files. They are append-only and time-ordered; the app keeps a byte offset per file and fetches only what was appended. |
| Firmware footprint | One new component, one new package, one include line. Zero edits to `sd_spi_card`, `sample.yaml` or the CSV format. The server starts only when a password is provisioned. |
| Build | Single binary, single manifest. The code ships in the fleet build but stays inert. A second build variant would double every release step for a rare deployment type. |

**Why the server is free to add.** `captive_portal` already auto-loads `web_server_base`, which
on ESP-IDF is `esp_http_server`. It is compiled into today's binary, and its auth middleware,
multipart parser and chunked responses are already there. The captive portal stops the listener
(`base_->deinit()`) once WiFi connects, so a home unit starts it back up only after a password is
set, and a building unit never does.

**What a home user gives up.** History is reachable only on the home WiFi. If remote viewing
becomes a requirement later, the Influx path can be layered on without touching the app's local
sync.

## 2. Wire contract

This table is the portability layer. The iOS app, the Android port and the firmware bench test
all conform to it. [`home-sync/fixtures/`](home-sync/fixtures/) holds it as bytes — three log
files, a listing, the expected rows and the fetch cases — so each side is written against files
rather than against the other side's source (see section 6).

Discovery is unchanged firmware behaviour: mDNS `_esphomelib._tcp`, TXT record carrying `mac`,
`project_name`, `project_version` (the firmware's own version, the same string as the log's
`# version:` line) and `version` (the ESPHome release). Only the two HTTP endpoints below are new.
Port 80.

| Request | Response | Notes |
|---|---|---|
| `GET /sd` | `200 application/json` — `{"mac":"F8B3B7C65CDC","files":[{"name":"F8B3B7C65CDC_260910_0412.txt","size":183426}]}` | Root of the card only, `.txt` only, in directory order. The app sorts by name: the name embeds boot time in UTC, so that order is chronological, and sorting on the unit would need a name table or a directory scan per file. No mtime: FATFS timestamps are not reliable before the first SNTP sync. |
| `GET /sd/<name>` | `200 text/csv`, `Transfer-Encoding: chunked` | Whole file streamed in 1460-byte chunks. No `Content-Length`; the listing carries size. |
| `GET /sd/<name>` with `Range: bytes=183000-` | `206`, `Content-Range: bytes 183000-183425/183426` | Open-ended ranges only. An offset at or past the current size returns `416`, which the app reads as "card replaced or file truncated". |
| `HEAD /sd/<name>` | `200` + `X-File-Size` | Optional cheap size probe for one file. The app normally uses the listing. |
| any, no or bad credentials | `401`, `WWW-Authenticate: Digest` | Username is always `samba`. Digest keeps the password off the wire on an unencrypted LAN. |
| any, card not mounted | `503`, `Retry-After: 30` | Mirrors the 30 s remount retry in `sd_spi_card`. |
| second request during a download | waits | The IDF server is one task serving one request at a time, so a second connection queues rather than being refused. The app keeps one connection anyway. |
| name with `/`, `..`, no `.txt`, or over 40 chars | `404` | Path validation before any filesystem call. |

### The file the app parses (already what the firmware writes)

```
# version: 1.99.99
# building: Home
# level: Ground
# zone: Living
time,ta,tg,rh,as,mrt,co2,lux,pm25,tvoc,nox,laeq,la90,la10
2026-09-10 04:15:00,23.41,23.88,51.2,0.083,24.12,612,184,3.2,104,1,38.4,33.1,42.7
2026-09-10 04:20:00,23.39,23.85,51.4,0.079,24.09,nan,181,3.1,103,1,37.9,32.8,41.9
```

One `snprintf` in `config/sample.yaml` writes each row, so the precision per column is fixed and
a conforming writer is byte-exact:

| Column | Measurand | Unit | Written as |
|---|---|---|---|
| `time` | timestamp, UTC | — | `%Y-%m-%d %H:%M:%S` |
| `ta` | air temperature | °C | `%.2f` |
| `tg` | globe temperature | °C | `%.2f` |
| `rh` | relative humidity | % | `%.1f` |
| `as` | air speed | m/s | `%.3f` |
| `mrt` | mean radiant temperature | °C | `%.2f` |
| `co2` | carbon dioxide | ppm | `%.0f` |
| `lux` | illuminance | lux | `%.0f` |
| `pm25` | PM2.5 | µg/m³ | `%.1f` |
| `tvoc`, `nox` | VOC and NOx index | index | `%.0f` |
| `laeq`, `la90`, `la10` | sound pressure level | dB(A) | `%.1f` |

- Timestamps are UTC from the DS1307, second resolution, one row per 5 minutes. About 85 bytes
  per row, 24 KB per day, 9 MB per year.
- File names are `<MAC>_<yymmdd>_<HHMM>.txt` at the card root, the MAC without colons and the
  boot time in UTC. The two-digit year sorts chronologically within the century.
- `nan` marks a sensor that failed that cycle, and `-nan` the same thing with the sign bit set,
  which is what newlib prints when a calibration lambda negates a NaN. The app stores either as
  null and draws a gap, never an interpolation.
- A new file is created per boot, after the first time sync. Rows are only written while the SD
  switch is on, so a gap in time is a gap in the record.
- Values are calibrated. The app applies no coefficients.

## 3. Firmware

Three new files, one new package, one line in `samba.yaml`, and a fourth entry in the credential
provisioning pattern that already exists.

```
components/sd_file_server/__init__.py       ~60 lines: schema; adds USE_WEBSERVER_AUTH and
                                            USE_WEBSERVER_AUTH_DIGEST defines
components/sd_file_server/sd_file_server.h  ~50 lines
components/sd_file_server/sd_file_server.cpp ~220 lines: list, stream, range, validation
config/fileserver.yaml                      ~70 lines: component, password global, api action,
                                            on_boot, fingerprint sensor
samba.yaml                                  +1 line in packages, one logger line
config/globals.yaml                         the fileserver_password global
docs/home-sync/bench.py                     the bench test, standard library only
CLAUDE.md, README.md                        credential #4
```

### Component design

- **Depends on `sd_spi_card` for one call,** `is_mounted()`. Files are read with `stat`,
  `fopen`, `fseek` and `fread` on `/sd`, the same VFS the append already uses. The listing reads
  the root directory with FatFs's own `f_readdir`, which returns each size in the same pass: the
  VFS `readdir` carries no size and a `stat` per file rescans the directory each time, which
  took seconds on a lab card with 90 files. FatFs is built re-entrant, so this sits safely beside
  the append. No new methods on the SD component.
- **Registers with `web_server_base` through `add_handler()`,** which routes every request
  through the existing auth middleware (`WebServerBase::set_auth_username/password`, active
  under `USE_WEBSERVER_AUTH`). The captive portal uses `add_handler_without_auth()` and is
  unaffected.
- **Streams with `httpd_resp_send_chunk` on the raw `httpd_req_t`.** ESPHome's IDF request
  wrapper exposes it via `operator httpd_req_t*`. Every ESPHome response class buffers the whole
  body in a `std::string`, which is why the n-serrette `sd_file_server` cannot serve a month-old
  log on this hardware.
- **One static 1460-byte buffer** as a `std::array` member, matching the TCP segment size the IDF
  server already uses for receives (`RECV_CHUNK_SIZE`). No heap after `setup()`. Nothing
  serialises downloads in the component: the IDF server is one task and serves requests one at
  a time by construction.
- **Handlers run on the httpd task,** not the main loop, so a download cannot trip the loop
  watchdog. The FAT VFS holds one lock per filesystem: the 5-minute append waits for at most one
  chunk read, roughly a millisecond at SPI speed.
- **Listing builds JSON with `snprintf`** into the same buffer, packing entries and sending a
  segment at a time (one chunk per entry cost a round trip each under Nagle). No ArduinoJson, no
  per-request allocation. `TCP_NODELAY` is set on every request so a short tail goes out at once.
- **Password gate.** `setup()` calls `base_->init()` only when the password global is non-empty.
  The api action sets the password, calls `init()` or `deinit()` accordingly, and flushes NVS
  through a `_save` script exactly as the OTA password does. The constructor gives
  `web_server_base` the user name and a null password: the middleware then wraps every
  authenticated route but passes everything until a password exists, so a fleet unit's captive
  portal is unchanged, and once a password is set it also guards the portal's firmware upload.
  With no password the `/sd` routes are not there at all (`canHandle` is false).
- **HEAD.** ESPHome's server registers only GET, POST and OPTIONS with the IDF server; the
  component registers HEAD through the same dispatcher after each start so it meets the same
  middleware and handlers.
- **No `loop()`.** The component is a handler plus a setup hook.

### The package, `config/fileserver.yaml`

Same shape as the token and OTA password blocks, so a reader of `config/ota.yaml` recognises it
immediately.

- `fileserver_password` global, `restore_value: yes`, `max_restore_data_length: 32`, initial
  `""`, kept in `config/globals.yaml` beside the other three credentials. Printable ASCII, 12 to
  32 characters, enforced in the action.
- `fileserver_set_password` api action. Empty string clears it and stops the listener.
- `on_boot` priority 600 hands the stored password to the component before `setup()` runs,
  matching the existing pattern.
- "File Server" text sensor, diagnostic, publishing `off` or the 8-digit FNV-1 fingerprint.
  Never the password. `samba home password` verifies against it.
- The component block itself: `sd_file_server: {id: sd_files, sd_spi_card_id: sd0}`. Port stays
  at 80 from `web_server_base`.

Nothing in `on_safe_mode` changes, and the component takes its base pointer through its
constructor, so there is no post-registration wiring to drift past the early return. The
half-wiring check in CLAUDE.md still runs as part of `/bump`.

### Provisioning, in the lab before shipping

1. **Calibrate and tag as usual.** Building becomes the household name, level and zone the room.
   `samba deploy` is unchanged.
2. **Set the file server password.** New `samba` CLI command, about 40 lines beside the token and
   OTA commands: `samba home password <host> [--generate]`. It calls the action and confirms the
   fingerprint.
3. **Print the pairing label.** A QR code encoding `samba://pair?mac=F8B3B7C65CDC&pw=…` goes on
   the underside of the unit. The app scans it once. Losing the label means a lab visit or a
   factory reset, which is the same rule the other three credentials already have.

### Bench test before the manifest lands on main

`docs/home-sync/bench.py HOST --password PW` runs the contract checks below that a client can
see (auth, listing, chunked and ranged transfers, `416`, `HEAD`, bad names, two downloads at
once) and `--soak MINUTES` polls the listing every 10 s; the heap figures it cannot see are on
the serial log, printed whenever the listener starts or stops.

- Fleet behaviour first: with no password set, confirm port 80 is closed after WiFi connects and
  free heap matches the previous build within noise.
- Set a password, confirm the listener starts without a reboot, and that a wrong password gets
  `401` on both endpoints.
- Stream a 700 KB file while the 5-minute sample fires. Row count and checksum on the phone equal
  the card read on a laptop. Watch for any `sd_spi_card` write failure.
- Range fetch at offset, at exact size, and past size. Expect `206`, `416` and `416`.
- Pull the card mid-download and expect `503` on the next request, then success after remount.
- Leave a unit under a 10-second poll for 24 hours. Heap must be flat; the captive portal must
  still come up after a WiFi loss.
- Run the safe-mode half-wiring script on the generated `main.cpp`.

## 4. ESP32 memory

The WROOM-32E has no PSRAM and the build already runs WiFi, a TLS HTTP client, the Noise API,
I2S audio and DSP. The additions are small, but they must be measured, not assumed.

| Item | When paid | Estimate | Basis |
|---|---|---|---|
| Flash, component code | Every unit, every build | 10–15 KB | Handler, listing; digest auth already compiled for captive portal. OTA image is 1.29 MB in a 7.75 MB app partition. |
| Static RAM, component object | Every unit | ~1.6 KB | 1460-byte buffer plus pointers and flags. Present whether or not the server runs. |
| httpd task stack | Home units only, while listener runs | 4.35 KB | ESPHome sets IDF's 4096 default plus 256. |
| httpd control block and header scratch | Home units only | ~3 KB | `CONFIG_HTTPD_MAX_REQ_HDR_LEN` is 1024 in this build; socket table sized for the default 7 sockets. |
| Per open connection, lwIP | Home units, during a sync | 2–4 KB | The app keeps one keep-alive connection. LRU purge is on, so a stale phone connection cannot pin sockets. |
| FAT file handles | During a download | 1 of 5 | `max_files` is 5. Append uses one transiently, download one; three spare. |
| Heap after `setup()` | Never | 0 | Chunk buffer is static, JSON is `snprintf`, paths are fixed `char` arrays. |

The captive portal already pays the httpd costs whenever a unit is in AP mode, so these figures
are not new territory for the hardware. The important guarantee is the gate: a building unit with
no password never starts the listener, and the fleet keeps today's heap profile.

Measure with a temporary `ESP_LOGI` of `esp_get_free_heap_size()` and
`heap_caps_get_largest_free_block(MALLOC_CAP_8BIT)` in the bench build, before and after a
password is set and again after the 24-hour soak. The largest free block is the number that
predicts field crashes; a shrinking one means fragmentation from something on the httpd path.

### Choices made for memory

- **No stock `web_server`.** It registers a state listener on every entity, builds JSON with
  ArduinoJson per request, keeps SSE client buffers, and exposes every switch and number as a
  POST endpoint, including factory reset. The last CSV row gives the same live value for nothing.
- **Chunked, not buffered.** Peak RAM is independent of file size.
- **One download at a time.** Bounded worst case rather than seven parallel reads contending on
  the SPI bus.
- **Digest over Basic** costs an MD5 per request, which is already linked for OTA, and nothing
  extra in RAM beyond ESPHome's nonce handling.

## 5. iOS app

Native Swift, iOS 17 and later. Two targets: a UI-free `SambaCore` package that owns the
contract, and a SwiftUI app that renders it. The split is what makes the Android port a
re-implementation against fixtures rather than a reverse-engineering.

### Stack

- **Discovery:** `NWBrowser` for `_esphomelib._tcp`; the TXT record carries `mac`,
  `project_name`, `project_version` and `version`, so the app matches a paired unit by MAC when
  its DHCP address changes and shows the firmware version it advertises.
- **HTTP:** `URLSession` with `httpMaximumConnectionsPerHost = 1`. Digest auth is handled by the
  system challenge delegate.
- **Store:** SQLite through GRDB. Chosen over SwiftData because the schema must be portable to
  Room on Android.
- **Charts:** Swift Charts.
- **Pairing:** VisionKit `DataScannerViewController` for the QR; password in the Keychain, never
  in the store.

### Info.plist

- `NSBonjourServices`: `_esphomelib._tcp`
- `NSLocalNetworkUsageDescription`
- `NSAppTransportSecurity` → `NSAllowsLocalNetworking`. Plain HTTP to a LAN host is permitted by
  Apple's rules.

### Schema (portable)

```sql
device(mac PK, name, host, last_seen, fw_version)
file(mac, name, size_seen, bytes_synced, fragment TEXT, PK(mac, name))
sample(mac, ts INTEGER, ta, tg, rh, as_, mrt, co2, lux, pm25, tvoc, nox, laeq, la90, la10,
       PK(mac, ts))
index sample(mac, ts DESC)
```

`ts` is Unix seconds. Duplicate timestamps are ignored on insert, so a refetch is harmless. The
`fragment` column carries a partial trailing line across syncs.

### Sync algorithm, in `SambaCore`

1. **Resolve the unit.** Browse Bonjour for up to 3 s, match TXT `mac`. Fall back to the last
   known host.
2. **List.** `GET /sd`. For each entry compare `size` with `bytes_synced`.
3. **Classify.** Unknown name: fetch from 0. Larger: fetch `Range: bytes=<bytes_synced>-`. Equal:
   skip. Smaller, or `416`: card replaced; reset the bookmark and fetch from 0.
4. **Parse streaming.** Prepend the stored fragment, split on newline, hold back the last partial
   line as the new fragment, skip `#` lines and the header. Upsert rows in one transaction per
   file.
5. **Advance.** Set `bytes_synced` to offset plus bytes received only after the transaction
   commits.
6. **Surface state.** Newest row is "now", with its age shown plainly. Older than 15 minutes reads
   as stale; an unreachable unit says so with the last successful sync time.

### Screens

- **Units.** Paired units with reachability and last sync. "Add unit" opens the QR scanner.
- **Now.** The 13 measurands from the newest row, in the units the lab uses: °C, %, m/s, ppm,
  µg/m³, index, lux, dB(A). Age of the reading is the most prominent secondary element.
- **History.** One measurand at a time, day, week and month ranges, gaps drawn as gaps.
  Aggregation is done in SQL on the phone, mirroring the hourly mean, min and max the lab's
  downsampler computes.
- **Settings.** Forget unit, export the local store as CSV, background refresh toggle.

### Milestones

| Week | Deliverable | Exit test |
|---|---|---|
| 1 | `SambaCore`: CSV parser, store, sync engine against the fixture files | Conformance tests pass on the fixtures; no networking yet |
| 2 | Discovery, digest auth, QR pairing, live sync against a bench unit | Cold sync of a 700 KB log, then a 5-minute incremental sync moving under 1 KB |
| 3 | Now and History screens, gaps, staleness, export | A week of real home data reads correctly against the SD card copy |
| 4 | Background refresh, edge cases, TestFlight | Card swap, reboot, address change and unreachable unit all recover without user action |

Background refresh uses `BGAppRefreshTask`. iOS schedules it opportunistically and the unit is
only reachable at home, so it is a convenience, not a guarantee. The reliable path is sync on
foreground.

## 6. Android pathway

Contract first, code second. The port is scoped by what it must conform to, not by what the Swift
code happens to do.

- **Fixtures in this repo.** `docs/home-sync/fixtures/` holds three log files (clean; `nan` rows,
  a `-nan` and a hole in the record; a partial last line), the listing JSON, the expected parsed
  rows, and the fetch cases including a resume mid-row and a `416`. `SambaCore`'s tests run
  against them from day one; the Android port runs the same files through the same assertions.
  The measurements are synthetic until a unit has logged a real day — the formats are not, and
  the directory's README says which is which.
- **Same schema, same algorithm.** The SQLite schema above is created verbatim by Room. The six
  sync steps are the spec; the Kotlin implementation follows them line by line.
- **Kotlin equivalents:** `NsdManager` for mDNS, OkHttp with its digest authenticator, Room, Vico
  for charts, ML Kit for the QR, `WorkManager` for background sync, which Android honours far
  better than iOS.
- **Local network permissions:** Android needs none for LAN HTTP; mDNS needs the multicast lock
  and, on 13+, nothing extra.

**Kotlin Multiplatform is the alternative,** moving `SambaCore` into shared Kotlin with SQLDelight
and Ktor and keeping SwiftUI and Compose as native shells. It saves the second implementation of
about 800 lines of core logic at the cost of a KMP toolchain in the iOS build. Worth it if Android
is committed within six months of iOS shipping; not worth it for an uncertain port. Either way the
fixtures and schema are the same, so the choice can be deferred to the point where Android is
funded.

## 7. Schedule and risks

| Stream | Effort | Depends on |
|---|---|---|
| Contract doc and fixtures | 1 day | Nothing. Do this first; both sides build against it. |
| Firmware component, package, `samba` CLI command | 3–4 days | Contract |
| Bench test and heap soak | 2 days, one of them unattended | Firmware on a physical unit |
| iOS app to TestFlight | 4 weeks | Week 1 needs only fixtures; week 2 onward needs a bench unit |
| Release via `/bump` | usual | Bench test passed; fleet units verified inert |

### Risks and the answer to each

- **Heap headroom on the running fleet build is unknown.** The gate keeps fleet units unchanged,
  and the soak test settles the home case before any unit ships. If the largest free block turns
  out tight, the buffer drops to 512 bytes at the cost of throughput.
- **Digest auth in ESPHome's IDF server is newer code.** Basic auth is a one-define fallback and
  the app's challenge handler covers both.
- **SD append and read contention.** The FAT lock serialises them; the bench test streams during
  a sample cycle to prove the append still lands.
- **Password on a lost label.** Same recovery as the API key and OTA password: factory reset and
  re-pair. Documented in the household setup sheet.
- **Router client isolation.** Some home routers block LAN-to-LAN traffic on guest networks. The
  setup sheet says to join the unit to the main network. The app's "unreachable" state names this
  as a likely cause.
- **Plain HTTP.** Data crosses the home LAN unencrypted. Digest protects the password; the
  measurements are room temperature and CO₂. Accepted, and stated in the sheet.

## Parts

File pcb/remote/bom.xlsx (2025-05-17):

 | SAMBA PCB REMOTE REV B4 PILOT RUN
Line # | Name | Description | Designator | Quantity | Case/Package | Value | Manufacturer 1 | Manufacturer Part Number 1 | Type | Notes
1 | CL10B105KA8NFNC | Ceramic Capacitor, Multilayer, Ceramic, 25V, 10% +Tol, 10% -Tol, X7R, 15% TC, 1uF, Surface Mount, 0603 | C1, C5, C17, C22 | 4 | 0603 | 1µF | Samsung | CL10B105KA8NFNC | SMD
2 | CC0603KRX7R7BB104 | Ceramic Capacitor, Multilayer, Ceramic, 16V, 10% +Tol, 10% -Tol, X7R, 15% TC, 0.1uF, Surface Mount, 0603 | C2, C4, C6, C8, C9, C10, C14, C15, C16, C18, C23, C24 | 12 | 0603 | 100nF | Yageo | CC0603KRX7R7BB104 | SMD
3 | GRM188R61A106ME69D | Ceramic Capacitor, Multilayer, Ceramic, 10V, 20% +Tol, 20% -Tol, X5R, 15% TC, 10uF, Surface Mount, 0603 | C3, C7, C21 | 3 | 0603 | 10µF | Murata | GRM188R61A106ME69D | SMD
4 | CL21B106KOQNNNE | Ceramic Capacitor, Multilayer, Ceramic, 16V, 10% +Tol, 10% -Tol, X7R, 15% TC, 10uF, Surface Mount, 0805 | C19, C20 | 2 | 0805 | 10µF | Samsung | CL21B106KOQNNNE | SMD
5 | LM4040C41IDBZR | Two Terminal Voltage Reference, 1 Output, 4.096V, BIPolar, PDSO3 | D1 | 1 | TSSOP |  | Texas Instruments | LM4040C41IDBZR | SMD
6 | ESD9B5.0ST5G | Trans Voltage Suppressor Diode, 5V V(RWM), Bidirectional, 1 Element, Silicon | D2, D3, D4, D5, D6 | 5 | SOD-923 |  | ON Semiconductor | ESD9B5.0ST5G | SMD
7 | 09455511103 | Telecom and Datacom Connector, 8 Contact(s), Female, Straight, Solder Terminal, Locking, Jack | J1 | 1 |  |  | HARTING Technology | 09455511103 | SMD+TH
8 | CC322522A-2R2K | General Purpose Inductor, 2.2uH, 10%, 1 Element, Ferrite-Core, SMD, 1110 | L1 | 1 | 1210 | 2.2uH | Bourns | CC322522A-2R2K | SMD
9 | FMMT493TA | Small Signal Bipolar Transistor, 1A I(C), 100V V(BR)CEO, 1-Element, NPN, Silicon | Q2, Q3 | 2 | SOT-23-3 |  | Diodes Zetex | FMMT493TA | SMD
10 | ERJ-3EKF2001V | Fixed Resistor, Metal Glaze/thick Film, 0.1W, 2000ohm, 75V, 1% +/-Tol, 100ppm/Cel, Surface Mount, 0603 | R1, R4, R14, R15, R19, R22, R34, R35 | 8 | 0603 | 2k | Panasonic | ERJ-3EKF2001V | SMD
11 | ERJ-3EKF1653V | Fixed Resistor, Metal Glaze/thick Film, 0.1W, 165000ohm, 75V, 1% +/-Tol, 100ppm/Cel, Surface Mount, 0603 | R6, R24 | 2 | 0603 | 165k | Panasonic | ERJ-3EKF1653V | SMD
12 | CRCW08051R00FKEAHP | Fixed Resistor, Metal Glaze/thick Film, 0.5W, 1ohm, 150V, 1% +/-Tol, 100ppm/Cel, Surface Mount, 0805 | R7, R25 | 2 | 0805 | 1R | Vishay Dale | CRCW08051R00FKEAHP | SMD
13 | RC0603FR-0710KL | Fixed Resistor, Metal Glaze/thick Film, 0.1W, 10000ohm, 75V, 1% +/-Tol, 100ppm/Cel, Surface Mount, 0603 | R8, R26, R32, R40 | 4 | 0603 | 10k | Yageo | RC0603FR-0710KL | SMD
14 | NTCG103NH471JT1 | NTC Thermistor, 470ohm, Surface Mount | R9, R27 | 2 | 0402 | 470R |  |  | TH | assembly drawing instructions for length of leads to solder into the board
15 | CRCW06033K60FKEAC | Fixed Resistor, Metal Glaze/thick Film, 0.1W, 3600ohm, 75V, 1% +/-Tol, 100ppm/Cel, Surface Mount, 0603 | R12, R31 | 2 | 0603 | 3.6k | Vishay | CRCW06033K60FKEAC | SMD
16 | AC0603FR-0775KL | Fixed Resistor, Metal Glaze/thick Film, 0.1W, 75000ohm, 75V, 1% +/-Tol, 100ppm/Cel, Surface Mount, 0603 | R13, R16, R33, R36 | 4 | 0603 | 75k | Yageo | AC0603FR-0775KL | SMD
17 | RC0805JR-075K1L | Fixed Resistor, Metal Glaze/thick Film, 0.125W, 5100ohm, 150V, 5% +/-Tol, 100ppm/Cel, Surface Mount, 0805 | R28, R39 | 2 | 0805 | 5.1k | Yageo | RC0805JR-075K1L | SMD
18 | Resistor 1k +/-1% 0603 100 mW | Chip Resistor, 1 KOhm, +/-1%, 0.1 W, -55 to 155 degC, 0603 (1608 Metric) | R29 | 1 | 0603 | 1k | Yageo | RC0603FR-071KL | SMD
19 | TT7-10KC3-11 | Lead Frame Ntc 10K 1 Ohm B TT7 3977K | R30 | 1 | Through hole | 10k | Tewa Sensors | TT7-10KC3-11 | SMD
20 | Resistor 0R +/- 5% 0603 100 mW | Chip Resistor, 0 Ohm, 0.1 W, -55 to 155 degC, 0603 (1608 Metric) | R41, R42 | 2 | 0603 | 0R | Yageo | RC0603JR-130RL | SMD
21 | ERJ-3EKF5900V | Fixed Resistor, Metal Glaze/thick Film, 0.1W, 590ohm, 75V, 1% +/-Tol, 100ppm/Cel, Surface Mount, 0603 | R43, R44, R47, R48 | 4 | 0603 | 590 | Panasonic | ERJ-3EKF5900V | SMD
22 | RMCF0603FT110R | Fixed Resistor, Metal Glaze/thick Film, 0.1W, 110ohm, 75V, 1% +/-Tol, 100ppm/Cel, Surface Mount, 0603 | R45, R46 | 2 | 0603 | 110 | Stackpole Electronics | RMCF0603FT110R | SMD
23 | CRM1206-FX-R910ELF | Fixed Resistor, Metal Glaze/thick Film, 0.5W, 0.91ohm, 0.675V, 1% +/-Tol, 100ppm/Cel, Surface Mount, 1206 | R50 | 1 | 1206 | 0.91 R | Bourns | CRM1206-FX-R910ELF | SMD
24 | TL974IPW | Operational Amplifier, 4 Func, 6000uV Offset-Max, BIPolar, PDSO14 | U1, U3 | 2 | TSSOP |  | Texas Instruments | TL974IPW | SMD
25 | SHT41A-AD1B-R3 | Board Mount Humidity Sensors 4th Gen Humidity and Temperature Sensor | U2 | 1 |  |  | Sensirion | SHT41A-AD1B-R3 | SMD | sensitive component - see soldering notes in assembly drawings
26 | LMV321WG-7 | Operational Amplifier, 1 Func, 9000uV Offset-Max, CMOS, PDSO5 | U4, U11 | 2 | LSSOP |  | Diodes | LMV321WG-7 | SMD
27 | TCA9509DGKR | Interface Circuit, PDSO8 | U5 | 1 | TSSOP |  | Texas Instruments | TCA9509DGKR | SMD
28 | ADS1115IDGSR | ADC, Delta-Sigma, 16-Bit, 1 Func, 4 Channel, Serial Access, PDSO10 | U7 | 1 | TSSOP |  | Texas Instruments | ADS1115IDGSR | SMD
29 | PCA9615DPZ | IC Redriver I2C 2CH 10TSSOP | U9 | 1 | 10-TSSOP |  | NXP Semiconductors | PCA9615DPZ | SMD
30 | LD39200PU33R | Fixed Positive LDO Regulator, 3.3V, 0.25V Dropout | U10 | 1 | HVSON |  | STMicroelectronics | LD39200PU33R | SMD

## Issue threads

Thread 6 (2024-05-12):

Onboard memory options

tom-parkinson, 2024-05-12:
There is currently no support for external memory in ESPHome. However, it's often requested and there appears to be some efforts towards getting it included in at least the dev channel.  Given we are redesigning the PCBs for SAMBA, it might be a good time to consider the options that might get native support in ESPHome and design for one of them. In order of preference:

1. SD card. Easiest to use and infinitely expandable. There's widespread support for [breakouts](https://www.adafruit.com/product/254) in Arduino that could be adapted for ESPHome. No obvious pull requests yet.
2. FRAM. More robust than EEPROM. Breakouts are [available](https://www.adafruit.com/product/1895) and there's a relatively mature [pull request](https://github.com/esphome/esphome/pull/4880).
3. EEPROM. Widely used. Breakouts are [available](https://www.adafruit.com/product/5146) with a mature [pull request](https://github.com/esphome/esphome/pull/6071).

The [discussion on the EEPROM pull request](https://github.com/esphome/esphome/pull/6071#issuecomment-2041927187) suggests there is a larger effort to include support for storage in ESPHome. We should plan accordingly.

tom-parkinson, 2025-10-01:
Support added with commit 5db9957 🎉

Closed 2025-10-01.

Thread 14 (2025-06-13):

Move calibration coefficients to global variables

tom-parkinson, 2025-06-13:
Calibration coefficients and other device-specific parameters like timezone and influx tags are stored in [substitutions](https://esphome.io/components/substitutions.html) in the main yaml file. This works just fine, but it prevents the use of a generic OTA approach (discussed in #8 ) because the compiled binary wouldn't contain those parameters.

Changing the setting of these parameters from substitutions to [Globals](https://esphome.io/components/globals.html) with `restore_value: true` would get around this by writing those values to flash. Setting the [flash.write.interval ](https://esphome.io/components/esphome.html#preferences-component) would avoid excessive writes to flash.

Doing this would allow for a simple generic config flashed to all SAMBAs that contained the calibration coefficients, captive portal for WiFi, and managed OTA updates.

Closed 2025-06-29.

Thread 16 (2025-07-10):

Crashing on InfluxDB upload

tom-parkinson, 2025-07-10:
My test SAMBA regularly crashes when uploading to InfluxDB. I know the custom component is causing the crash because it occurs at 5-min points e.g. 10:35, 10:50 etc. There must be something about the http request that is holding up the loop and causing it to crash, perhaps memory related.

At its simplest, it could be triggering [`watchdog_timeout`](https://esphome.io/components/http_request.html) . But it requires debugging to determine what the problem is. There is a lot happening on the device so it's possible we're pushing the ESP32 to its limit. Recent performance improvements in ESPHome (2025.7.1) should help. Use of [`debug`](https://esphome.io/components/debug.html) or the forthcoming `runtime_stats` should help narrow down the cause.

tom-parkinson, 2025-07-15:
I actually think this is an issue with the Kent Vale WiFi. I'll close for now but continue to monitor on other networks.

Closed 2025-07-15.

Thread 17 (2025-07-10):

Upgrade to v2 of SPL component

tom-parkinson, 2025-07-10:
Development seems to have stalled, but the author of the SPL component has update it to 2.0.0. Of interest is...

> Optimised buffer memory management, which reduces memory (re)allocations and improves performance

We should upgrade the SPL component on SAMBA to take advantage of the performance boost.

Closed 2025-07-17.

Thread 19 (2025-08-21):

Sporadic crash from i2c bus error

tom-parkinson, 2025-08-21:
There is an infrequent crash that occurs from some issue on the i2c line. I'm not sure what the problem is, but the log from the crash is below for future debugging.

```
[14:09:56]Guru Meditation Error: Core  0 panic'ed (Interrupt wdt timeout on CPU0).

[14:09:56]Core  0 register dump:
[14:09:57]PC      : 0x40081a0d  PS      : 0x00050d34  A0      : 0x40088510  A1      : 0x3ffb2180
WARNING Decoded 0x40081a0d: i2c_isr_handler_default at /Users/tom/.platformio/packages/framework-espidf/components/driver/i2c/i2c.c:586
[14:09:57]A2      : 0x3ffc7dc8  A3      : 0x0000cdcd  A4      : 0x3ffb0050  A5      : 0x00000080
[14:09:57]A6      : 0x00000000  A7      : 0x00000000  A8      : 0x00000000  A9      : 0x00000001
[14:09:57]A10     : 0x3ffb0050  A11     : 0xffffffff  A12     : 0x3ffb218c  A13     : 0x00060d23
[14:09:57]A14     : 0x3ffdc010  A15     : 0x00000000  SAR     : 0x0000001b  EXCCAUSE: 0x00000005
[14:09:57]EXCVADDR: 0x00000000  LBEG    : 0x4000c2e0  LEND    : 0x4000c2f6  LCOUNT  : 0xffffffff
[14:09:57]Core  0 was running in ISR context:
[14:09:57]EPC1    : 0x40112db3  EPC2    : 0x00000000  EPC3    : 0x00000000  EPC4    : 0x40081a0d

[14:09:57]Backtrace: 0x40081a0a:0x3ffb2180 0x4008850d:0x3ffb21c0 0x40082345:0x3ffc0c30 0x4008ca67:0x3ffc0c40 0x40101095:0x3ffc0c60 0x40101a30:0x3ffc0c80 0x40102030:0x3ffc0cf0 0x400dde44:0x3ffc0d30 0x4019368b:0x3ffc0d50 0x401935f3:0x3ffc0d80 0x400ddcc2:0x3ffc0db0 0x400d362e:0x3ffc0dd0 0x400d37d2:0x3ffc0e00 0x400d37f5:0x3ffc0e20 0x400d3812:0x3ffc0e40 0x40194b2d:0x3ffc0e60 0x400f06f2:0x3ffc0e80 0x400f102f:0x3ffc0eb0 0x400ee36d:0x3ffc0f00 0x400ee474:0x3ffc0f20 0x400f2792:0x3ffc0f50 0x400d9846:0x3ffc0f70
WARNING Found stack trace! Trying to decode it
WARNING Decoded 0x40081a0a: i2c_isr_handler_default at /Users/tom/.platformio/packages/framework-espidf/components/driver/i2c/i2c.c:584
WARNING Decoded 0x4008850d: _xt_lowint1 at /Users/tom/.platformio/packages/framework-espidf/components/xtensa/xtensa_vectors.S:1240
WARNING Decoded 0x40082345: shared_intr_isr at /Users/tom/.platformio/packages/framework-espidf/components/esp_hw_support/intr_alloc.c:454
WARNING Decoded 0x4008ca67: vPortClearInterruptMaskFromISR at /Users/tom/.platformio/packages/framework-espidf/components/freertos/FreeRTOS-Kernel/portable/xtensa/include/freertos/portmacro.h:560
 (inlined by) vPortExitCritical at /Users/tom/.platformio/packages/framework-espidf/components/freertos/FreeRTOS-Kernel/portable/xtensa/port.c:514
WARNING Decoded 0x40101095: i2c_hw_disable at /Users/tom/.platformio/packages/framework-espidf/components/driver/i2c/i2c.c:263
WARNING Decoded 0x40101a30: i2c_hw_fsm_reset at /Users/tom/.platformio/packages/framework-espidf/components/driver/i2c/i2c.c:711
WARNING Decoded 0x40102030: i2c_master_cmd_begin at /Users/tom/.platformio/packages/framework-espidf/components/driver/i2c/i2c.c:1609
WARNING Decoded 0x400dde44: esphome::i2c::IDFI2CBus::writev(unsigned char, esphome::i2c::WriteBuffer*, unsigned int, bool) at /Users/tom/r_projects/samba/.esphome/build/samba/src/esphome/components/i2c/i2c_bus_esp_idf.cpp:242
 (inlined by) esphome::i2c::IDFI2CBus::writev(unsigned char, esphome::i2c::WriteBuffer*, unsigned int, bool) at /Users/tom/r_projects/samba/.esphome/build/samba/src/esphome/components/i2c/i2c_bus_esp_idf.cpp:188
WARNING Decoded 0x4019368b: esphome::i2c::I2CBus::write(unsigned char, unsigned char const*, unsigned int, bool) at /Users/tom/r_projects/samba/.esphome/build/samba/src/esphome/components/i2c/i2c_bus.h:77
WARNING Decoded 0x401935f3: esphome::i2c::I2CDevice::write(unsigned char const*, unsigned int, bool) at /Users/tom/r_projects/samba/.esphome/build/samba/src/esphome/components/i2c/i2c.h:190
 (inlined by) esphome::i2c::I2CDevice::read_register(unsigned char, unsigned char*, unsigned int, bool) at /Users/tom/r_projects/samba/.esphome/build/samba/src/esphome/components/i2c/i2c.cpp:11
WARNING Decoded 0x400ddcc2: esphome::i2c::I2CDevice::read_bytes_16(unsigned char, unsigned short*, unsigned char) at /Users/tom/r_projects/samba/.esphome/build/samba/src/esphome/components/i2c/i2c.cpp:45
WARNING Decoded 0x400d362e: esphome::i2c::I2CDevice::read_byte_16(unsigned char, unsigned short*) at /Users/tom/r_projects/samba/.esphome/build/samba/src/esphome/components/i2c/i2c.h:250
 (inlined by) esphome::ads1115::ADS1115Component::request_measurement(esphome::ads1115::ADS1115Multiplexer, esphome::ads1115::ADS1115Gain, esphome::ads1115::ADS1115Resolution, esphome::ads1115::ADS1115Samplerate) at /Users/tom/r_projects/samba/.esphome/build/samba/src/esphome/components/ads1115/ads1115.cpp:171
WARNING Decoded 0x400d37d2: esphome::ads1115::ADS1115Sensor::sample() at /Users/tom/r_projects/samba/.esphome/build/samba/src/esphome/components/ads1115/sensor/ads1115_sensor.cpp:11
WARNING Decoded 0x400d37f5: esphome::ads1115::ADS1115Sensor::update() at /Users/tom/r_projects/samba/.esphome/build/samba/src/esphome/components/ads1115/sensor/ads1115_sensor.cpp:15
WARNING Decoded 0x400d3812: non-virtual thunk to esphome::ads1115::ADS1115Sensor::update() at /Users/tom/r_projects/samba/.esphome/build/samba/src/esphome/components/ads1115/sensor/ads1115_sensor.h:20
WARNING Decoded 0x40194b2d: std::_Function_handler<void (), esphome::PollingComponent::start_poller()::{lambda()#1}>::_M_invoke(std::_Any_data const&) at /Users/tom/r_projects/samba/.esphome/build/samba/src/esphome/core/component.cpp:382
 (inlined by) __invoke_impl<void, esphome::PollingComponent::start_poller()::<lambda()>&> at /Users/tom/.platformio/packages/toolchain-xtensa-esp-elf/xtensa-esp-elf/include/c++/13.2.0/bits/invoke.h:61
 (inlined by) __invoke_r<void, esphome::PollingComponent::start_poller()::<lambda()>&> at /Users/tom/.platformio/packages/toolchain-xtensa-esp-elf/xtensa-esp-elf/include/c++/13.2.0/bits/invoke.h:111
 (inlined by) _M_invoke at /Users/tom/.platformio/packages/toolchain-xtensa-esp-elf/xtensa-esp-elf/include/c++/13.2.0/bits/std_function.h:290
WARNING Decoded 0x400f06f2: std::function<void ()>::operator()() const at /Users/tom/.platformio/packages/toolchain-xtensa-esp-elf/xtensa-esp-elf/include/c++/13.2.0/bits/std_function.h:591
 (inlined by) esphome::Scheduler::execute_item_(esphome::Scheduler::SchedulerItem*) at /Users/tom/r_projects/samba/.esphome/build/samba/src/esphome/core/scheduler.cpp:431
WARNING Decoded 0x400f102f: esphome::Scheduler::call() at /Users/tom/r_projects/samba/.esphome/build/samba/src/esphome/core/scheduler.cpp:351 (discriminator 1)
WARNING Decoded 0x400ee36d: esphome::Application::before_loop_tasks_(unsigned long) at /Users/tom/r_projects/samba/.esphome/build/samba/src/esphome/core/application.cpp:390
WARNING Decoded 0x400ee474: esphome::Application::loop() at /Users/tom/r_projects/samba/.esphome/build/samba/src/esphome/core/application.cpp:105
WARNING Decoded 0x400f2792: loop() at /Users/tom/r_projects/samba/.esphome/build/samba/config/esp32.yaml:70
WARNING Decoded 0x400d9846: esphome::loop_task(void*) at /Users/tom/r_projects/samba/.esphome/build/samba/src/esphome/components/esp32/core.cpp:82 (discriminator 1)

[14:10:00]Core  1 register dump:
[14:10:00]PC      : 0x40082e29  PS      : 0x00060e34  A0      : 0x80082e54  A1      : 0x3ffdd2c0
WARNING Decoded 0x40082e29: esp_crosscore_int_send at /Users/tom/.platformio/packages/framework-espidf/components/esp_system/crosscore_int.c:112
[14:10:01]A2      : 0x00000001  A3      : 0x00000001  A4      : 0x000eecaf  A5      : 0x00000004
[14:10:01]A6      : 0x3ffb5600  A7      : 0x3ffb5604  A8      : 0x3ffb51b8  A9      : 0x00000000
[14:10:01]A10     : 0x3ffb0328  A11     : 0xffffffff  A12     : 0xb33fffff  A13     : 0x00060e23
[14:10:01]A14     : 0x00000003  A15     : 0x0000abab  SAR     : 0x00000018  EXCCAUSE: 0x00000005
[14:10:01]EXCVADDR: 0x00000000  LBEG    : 0x4000c2e0  LEND    : 0x4000c2f6  LCOUNT  : 0x00000000

[14:10:01]Backtrace: 0x40082e26:0x3ffdd2c0 0x40082e51:0x3ffdd2e0 0x4008c30a:0x3ffdd300 0x40104adf:0x3ffdd340 0x400de502:0x3ffdd380 0x400de78b:0x3ffdd3b0
WARNING Found stack trace! Trying to decode it
WARNING Decoded 0x40082e26: esp_crosscore_int_send at /Users/tom/.platformio/packages/framework-espidf/components/esp_system/crosscore_int.c:112
WARNING Decoded 0x40082e51: esp_crosscore_int_send_yield at /Users/tom/.platformio/packages/framework-espidf/components/esp_system/crosscore_int.c:120
WARNING Decoded 0x4008c30a: xQueueReceive at /Users/tom/.platformio/packages/framework-espidf/components/freertos/FreeRTOS-Kernel/queue.c:1620 (discriminator 1)
WARNING Decoded 0x40104adf: i2s_channel_read at /Users/tom/.platformio/packages/framework-espidf/components/esp_driver_i2s/i2s_common.c:1256
WARNING Decoded 0x400de502: esphome::i2s_audio::I2SAudioMicrophone::read_(unsigned char*, unsigned int, unsigned long) at /Users/tom/r_projects/samba/.esphome/build/samba/src/esphome/components/i2s_audio/microphone/i2s_audio_microphone.cpp:441
WARNING Decoded 0x400de78b: esphome::i2s_audio::I2SAudioMicrophone::mic_task(void*) at /Users/tom/r_projects/samba/.esphome/build/samba/src/esphome/components/i2s_audio/microphone/i2s_audio_microphone.cpp:362 (discriminator 1)
```

tom-parkinson, 2025-10-01:
This seems to have resolved itself with the new i2c stack in ESPHome 2025.09.01. I'll continue monitoring and reopen if I can get a crash log.

Closed 2025-10-01.

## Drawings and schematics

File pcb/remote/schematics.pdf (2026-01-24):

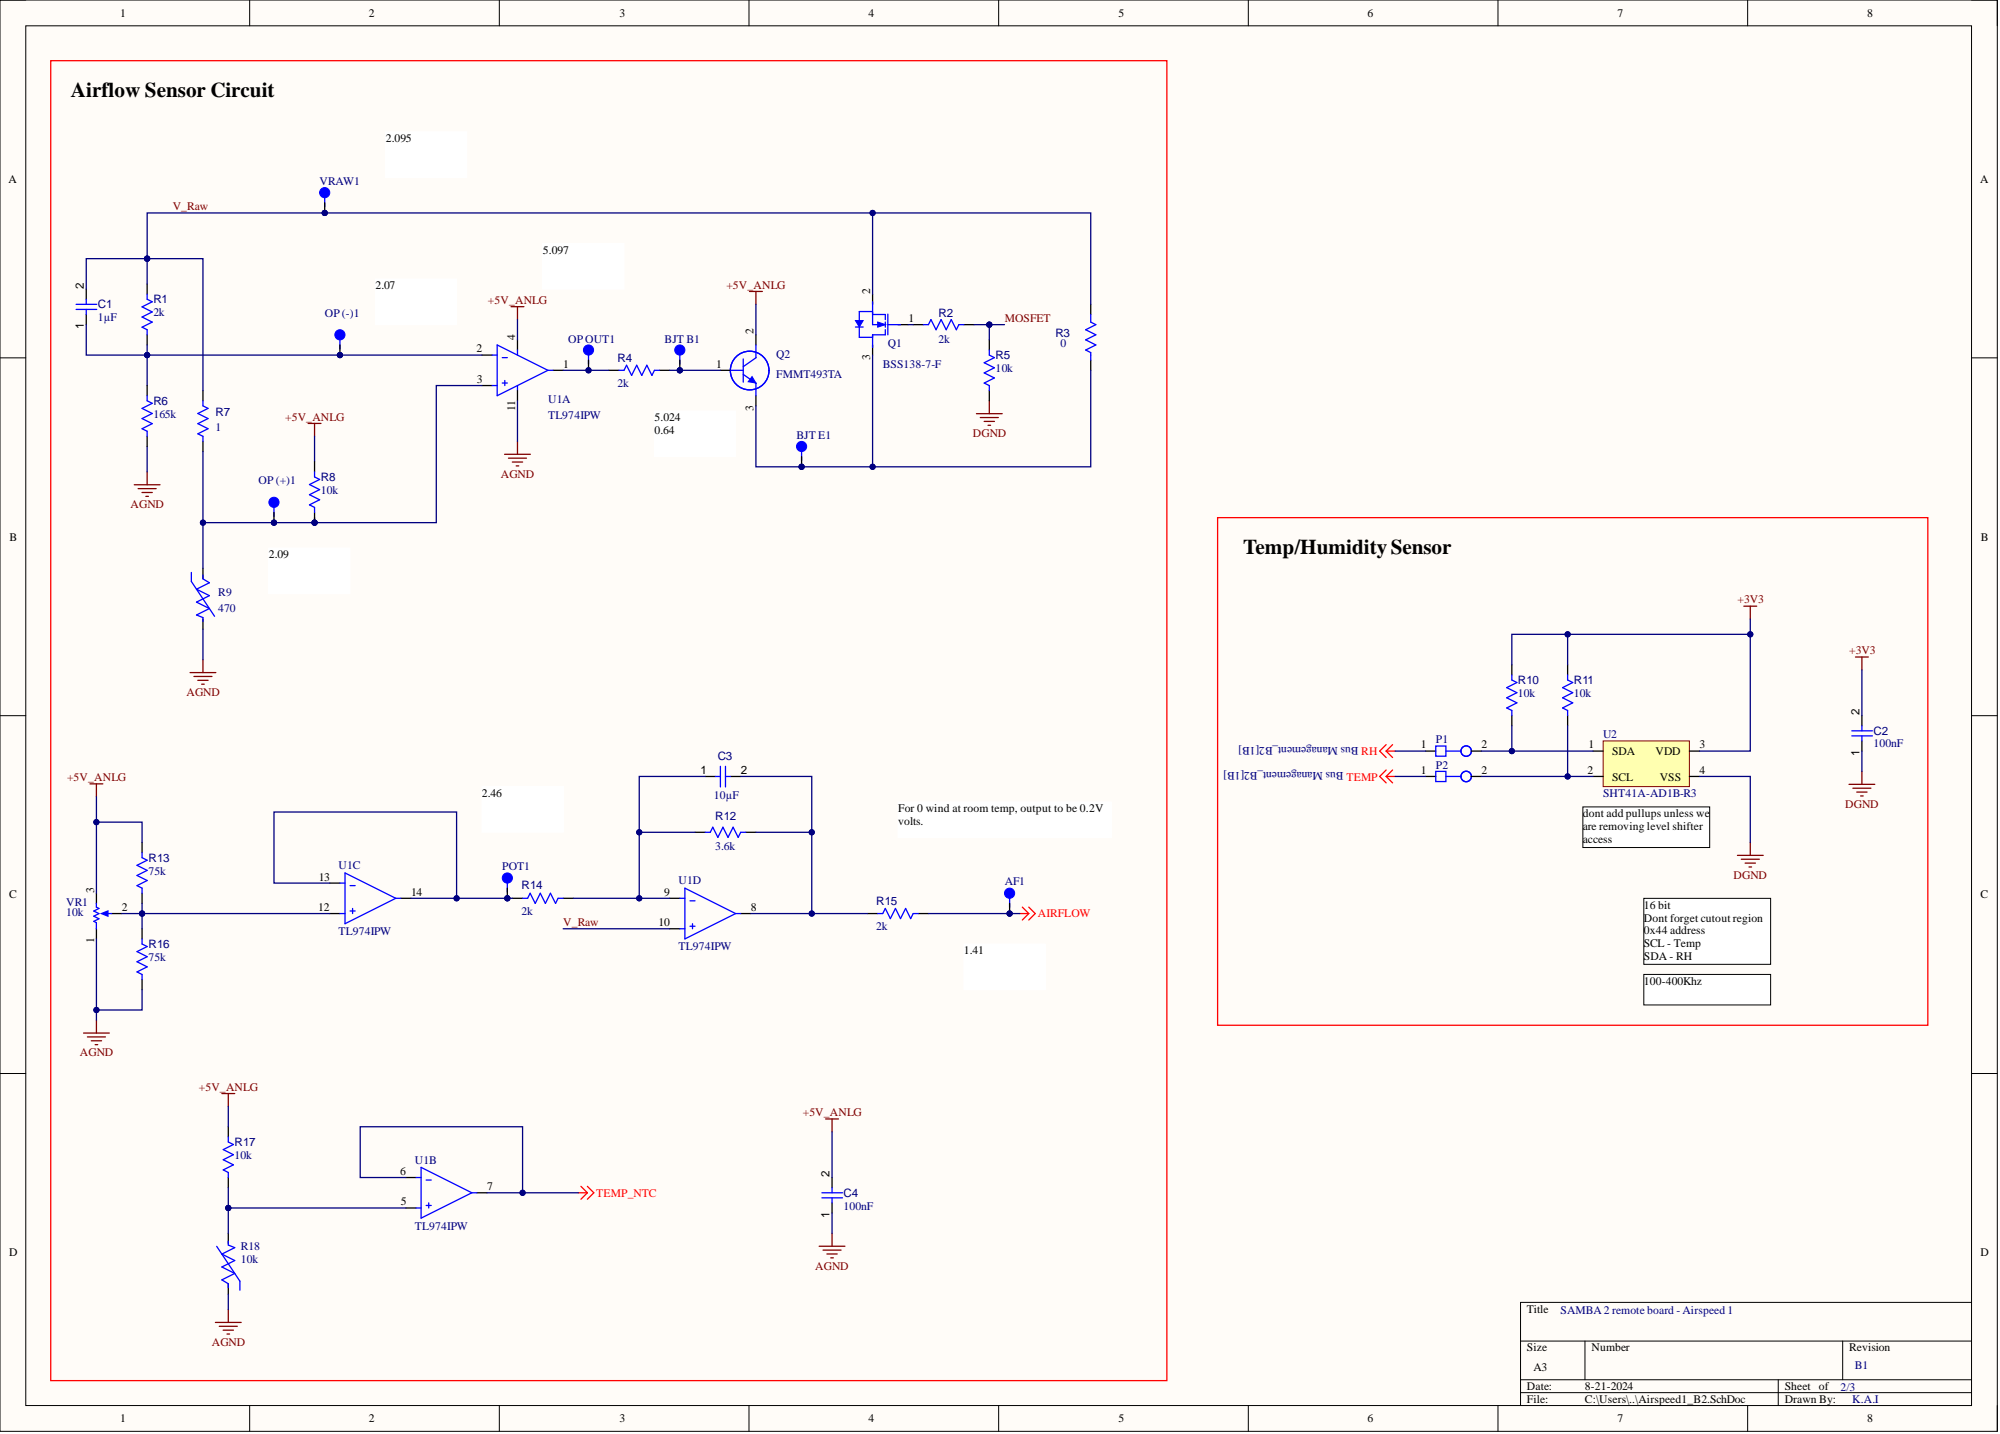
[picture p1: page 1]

RH ] B1[ 2B_t ne megana MsuB

TEMP ] B1[ 2B_t ne megana MsuB

SHT41A-AD1B-R3
dont add pullups unless we
are removing levelshifter
access

For 0 wind at room temp, output to be 0.2V
volts.

16 bit
Dont forget cutout region
0x44 address
SCL - Temp
SDA - RH

SAMBA 2 remote board - Airspeed 1

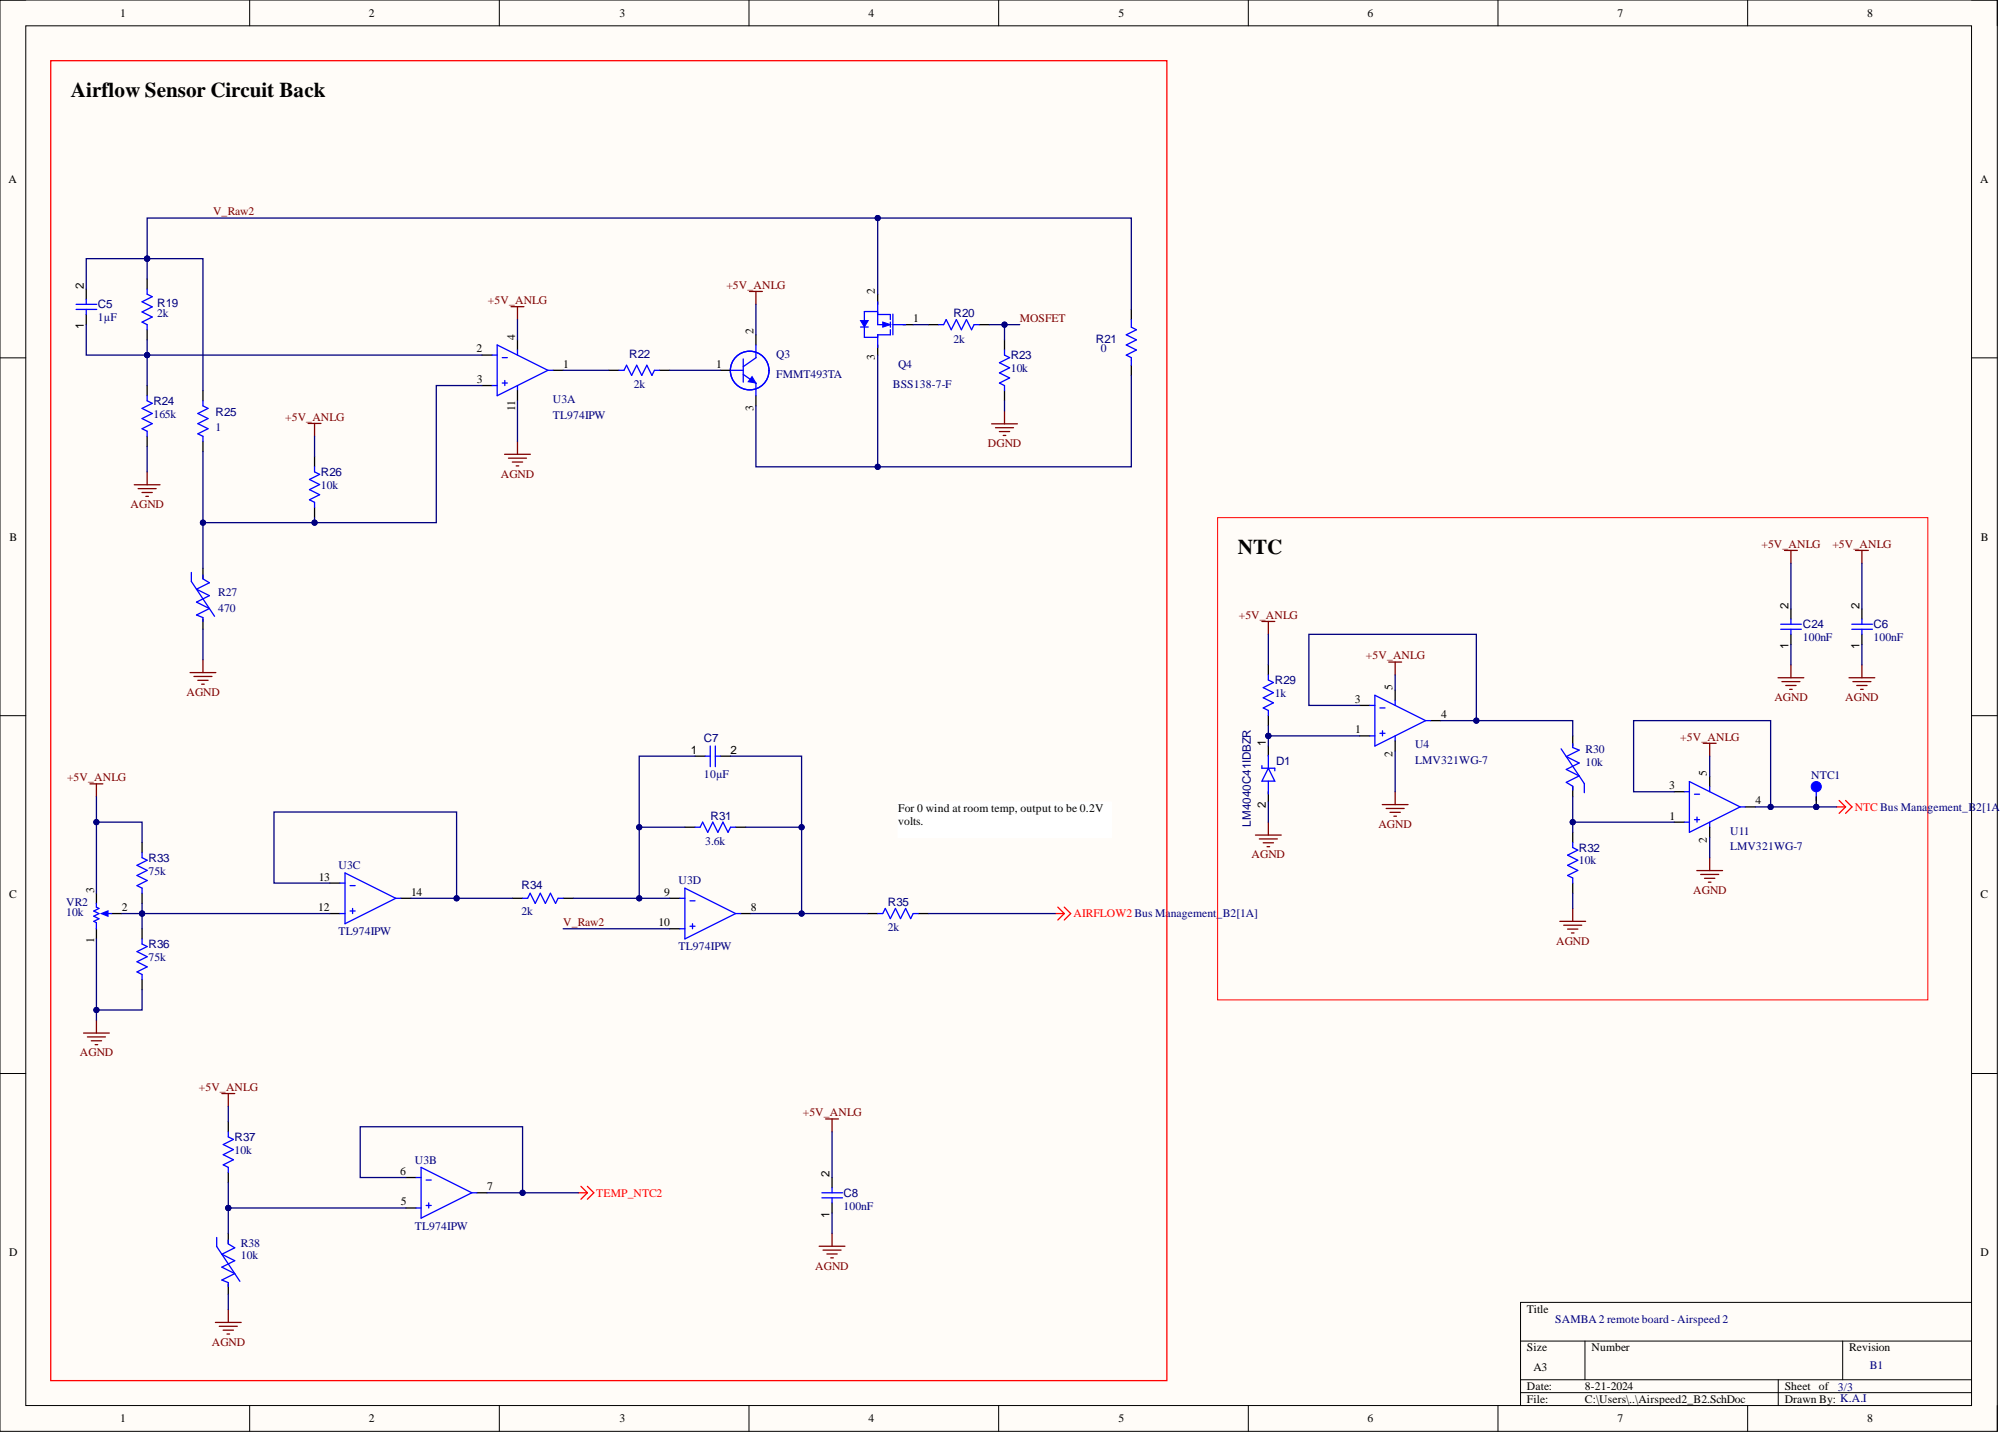
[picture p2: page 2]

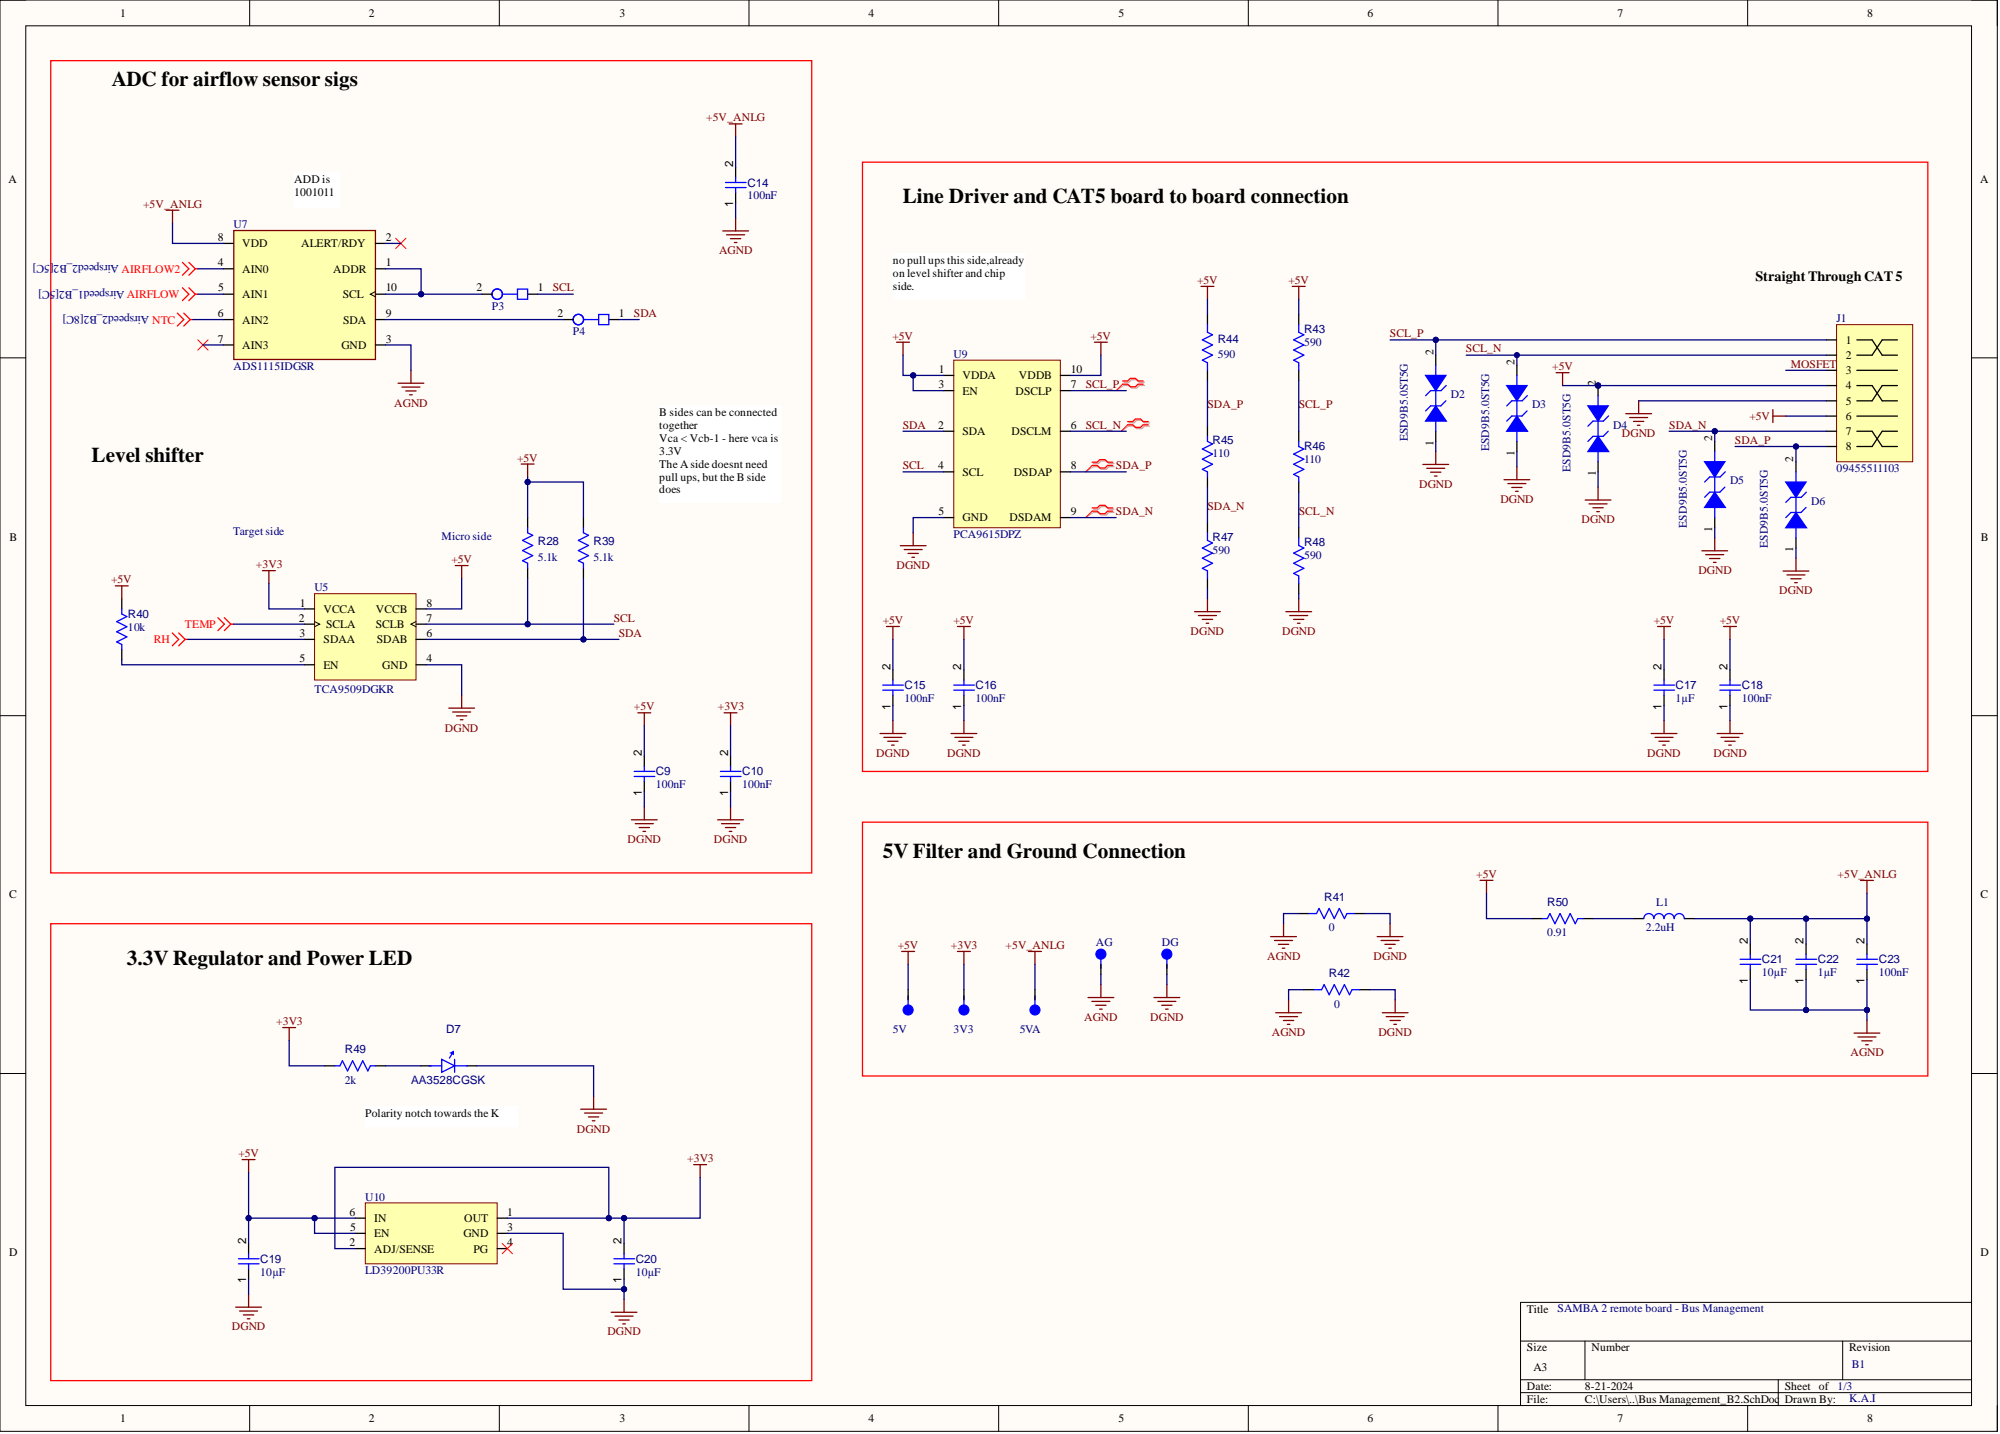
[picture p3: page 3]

ADC for airflow sensor sigs

Line Driver and CAT5 board to board connection

no pull ups this side,already
on levelshifter and chip
side.

B sides can be connected
together
Vca < Vcb-1 - here vca is
The A side doesnt need
pull ups, but the B side
does

3.3V Regulator and Power LED

Polarity notch towards the K

SAMBA 2 remote board - Bus Management
Title

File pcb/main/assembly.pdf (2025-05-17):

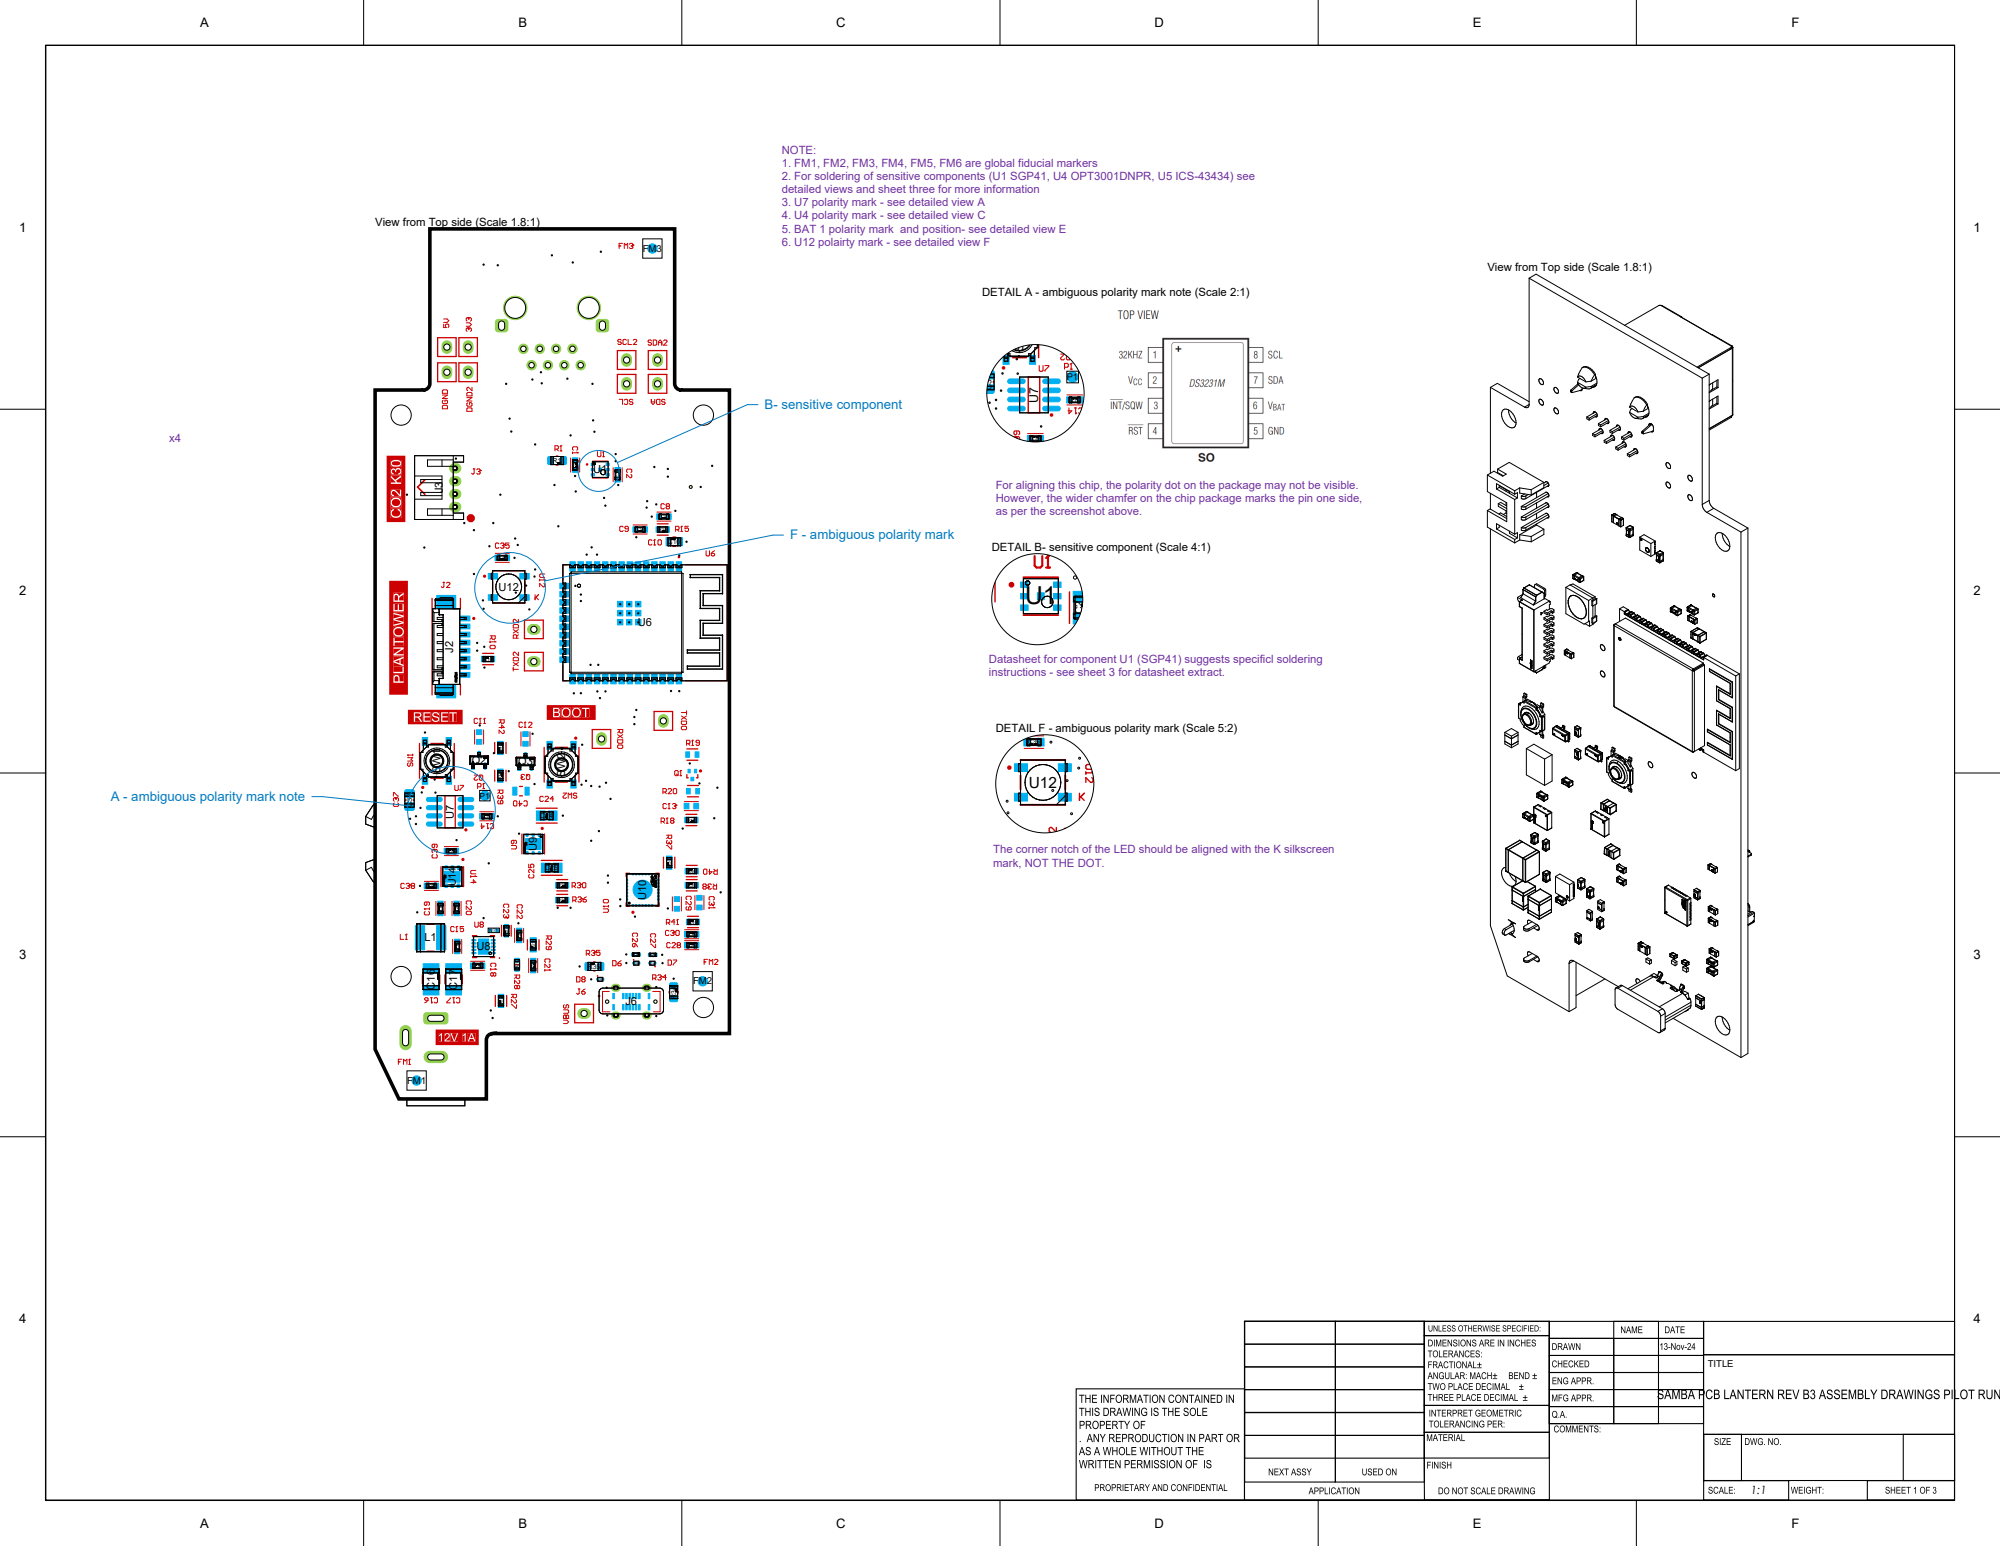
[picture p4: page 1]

NOTE:
1. FM1, FM2, FM3, FM4, FM5, FM6 are global fiducial markers
2. For soldering of sensitive components (U1 SGP41, U4 OPT3001DNPR, U5 ICS-43434) see
detailed views and sheet three for more information
3. U7 polarity mark - see detailed view A
4. U4 polarity mark - see detailed view C
5. BAT 1 polarity mark and position- see detailed view E
6. U12 polairty mark - see detailed view F

View from Top side (Scale 1.8:1)

DETAIL A - ambiguous polarity mark note (Scale 2:1)

For aligning this chip, the polarity dot on the package may not be visible.
However, the wider chamfer on the chip package marks the pin one side,
as per the screenshot above. C2

DETAIL B- sensitive component (Scale 4:1)

Datasheet for component U1 (SGP41) suggests specificl soldering
instructions - see sheet 3 for datasheet extract.

DETAIL F - ambiguous polarity mark (Scale 5:2)

A - ambiguous polarity mark note

The corner notch of the LED should be aligned with the K silkscreen
mark, NOT THE DOT.

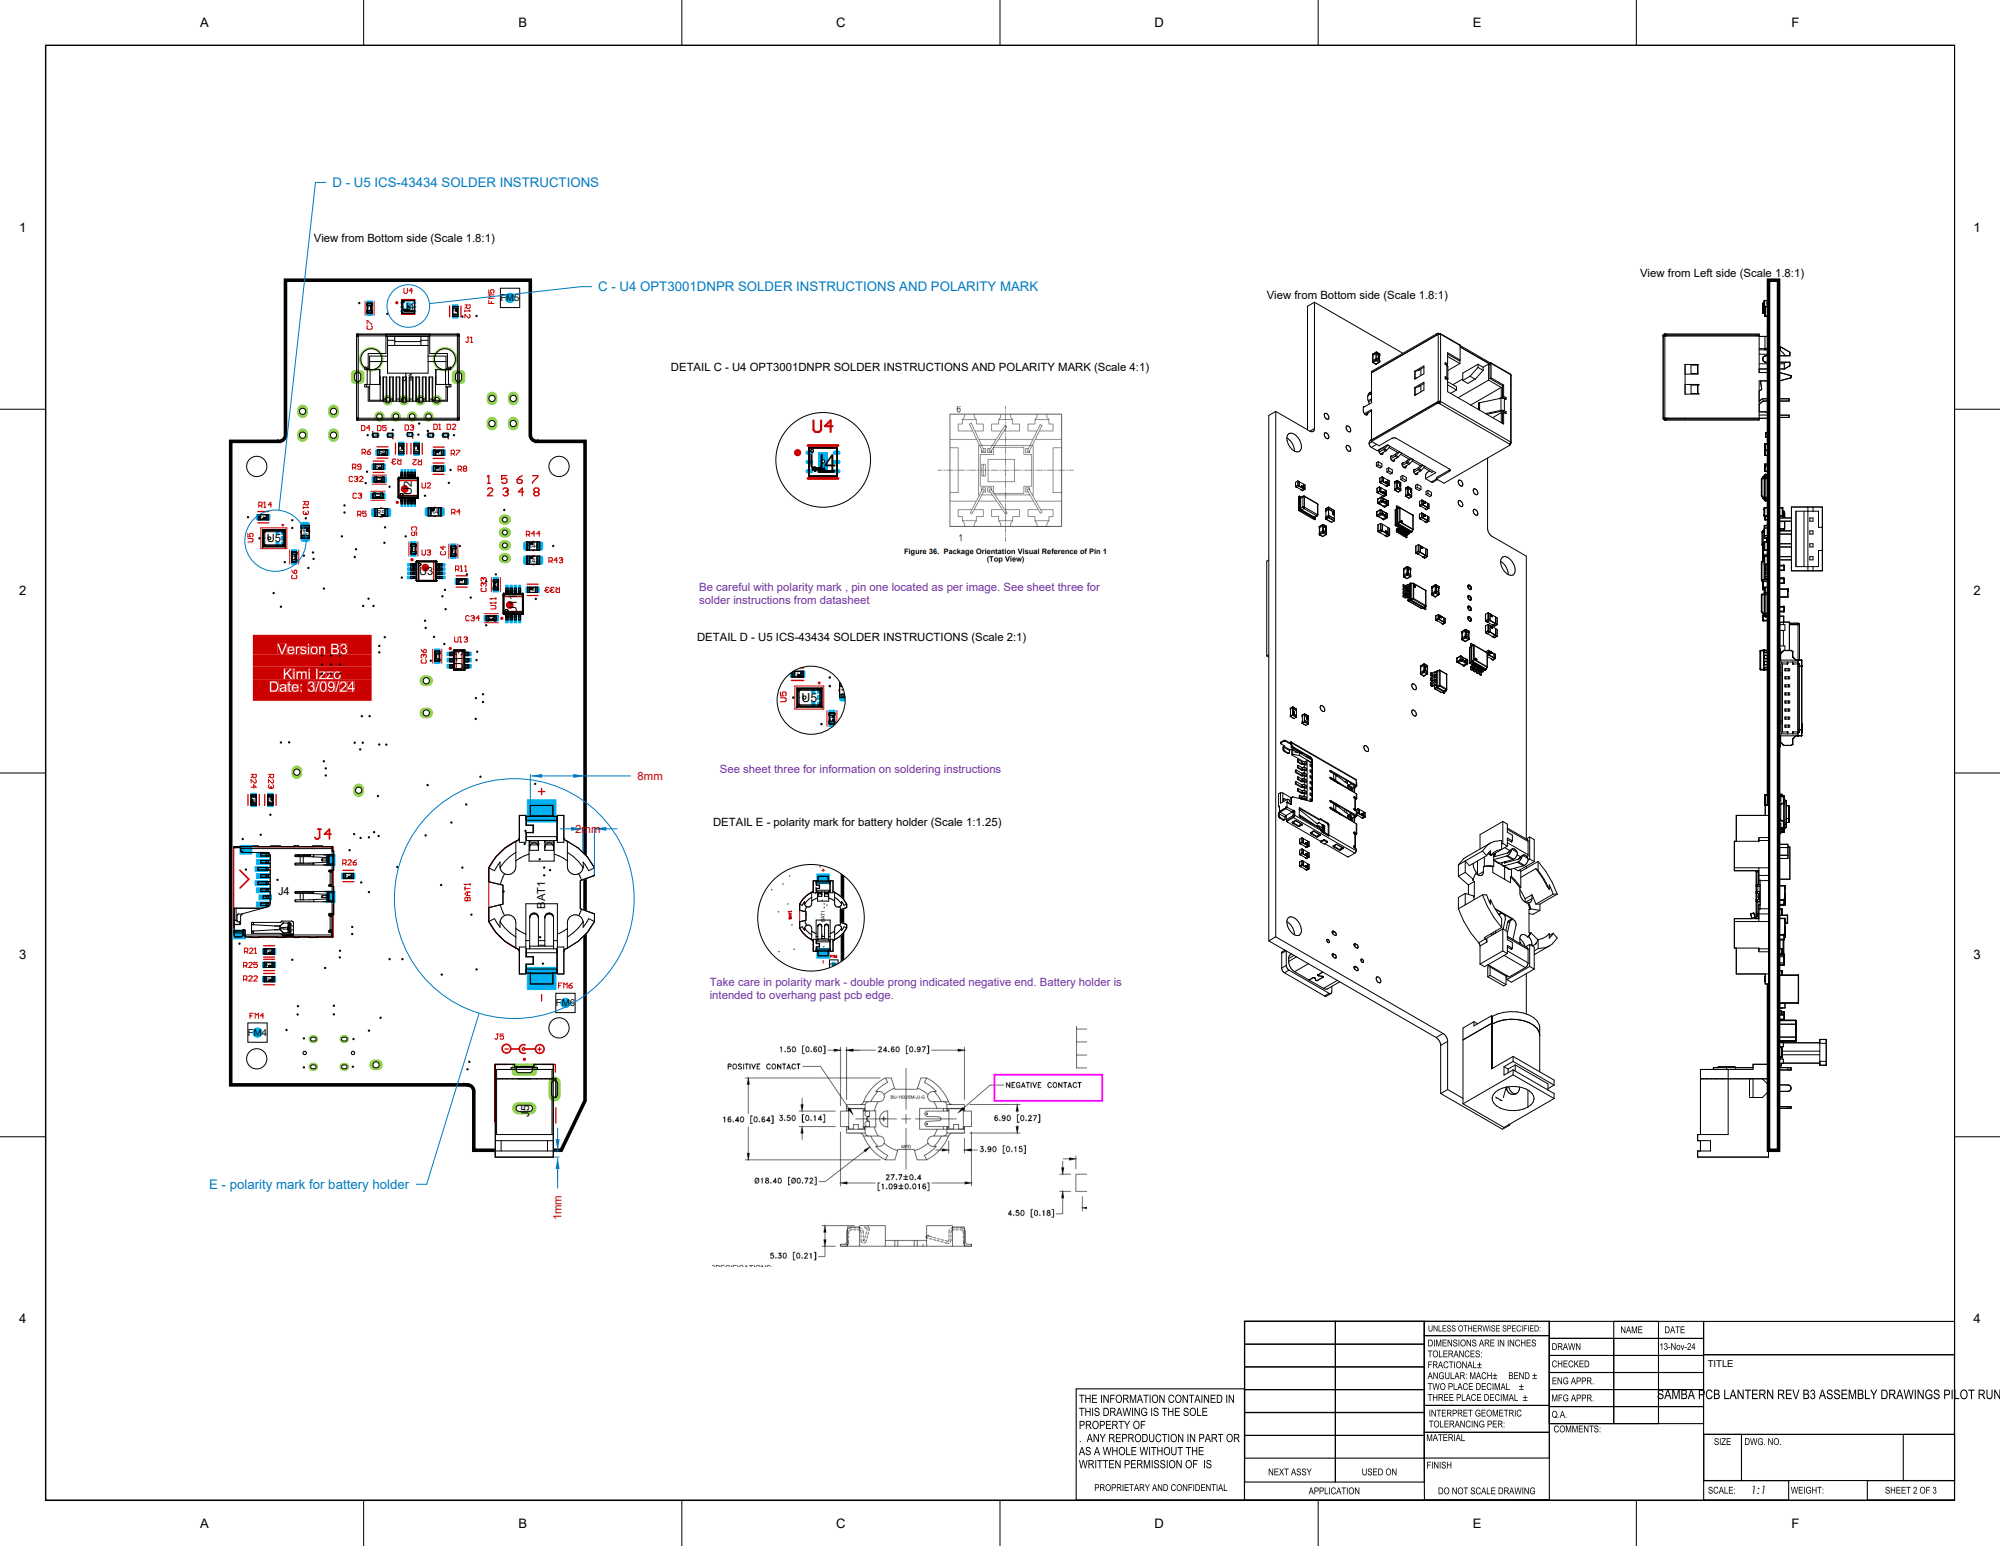
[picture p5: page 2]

View from Bottom side (Scale 1.8:1)

View from Left side (Scale 1.8:1)

C - U4 OPT3001DNPR SOLDER INSTRUCTIONS AND POLARITY MARK

DETAIL C - U4 OPT3001DNPR SOLDER INSTRUCTIONS AND POLARITY MARK (Scale 4:1)

Be careful with polarity mark , pin one located as per image. See sheet three for
solder instructions from datasheet

DETAIL D - U5 ICS-43434 SOLDER INSTRUCTIONS (Scale 2:1)

See sheet three for information on soldering instructions BAT1

DETAIL E - polarity mark for battery holder (Scale 1:1.25)

Take care in polarity mark - double prong indicated negative end. Battery holder is
intended to overhang past pcb edge.

E - polarity mark for battery holder

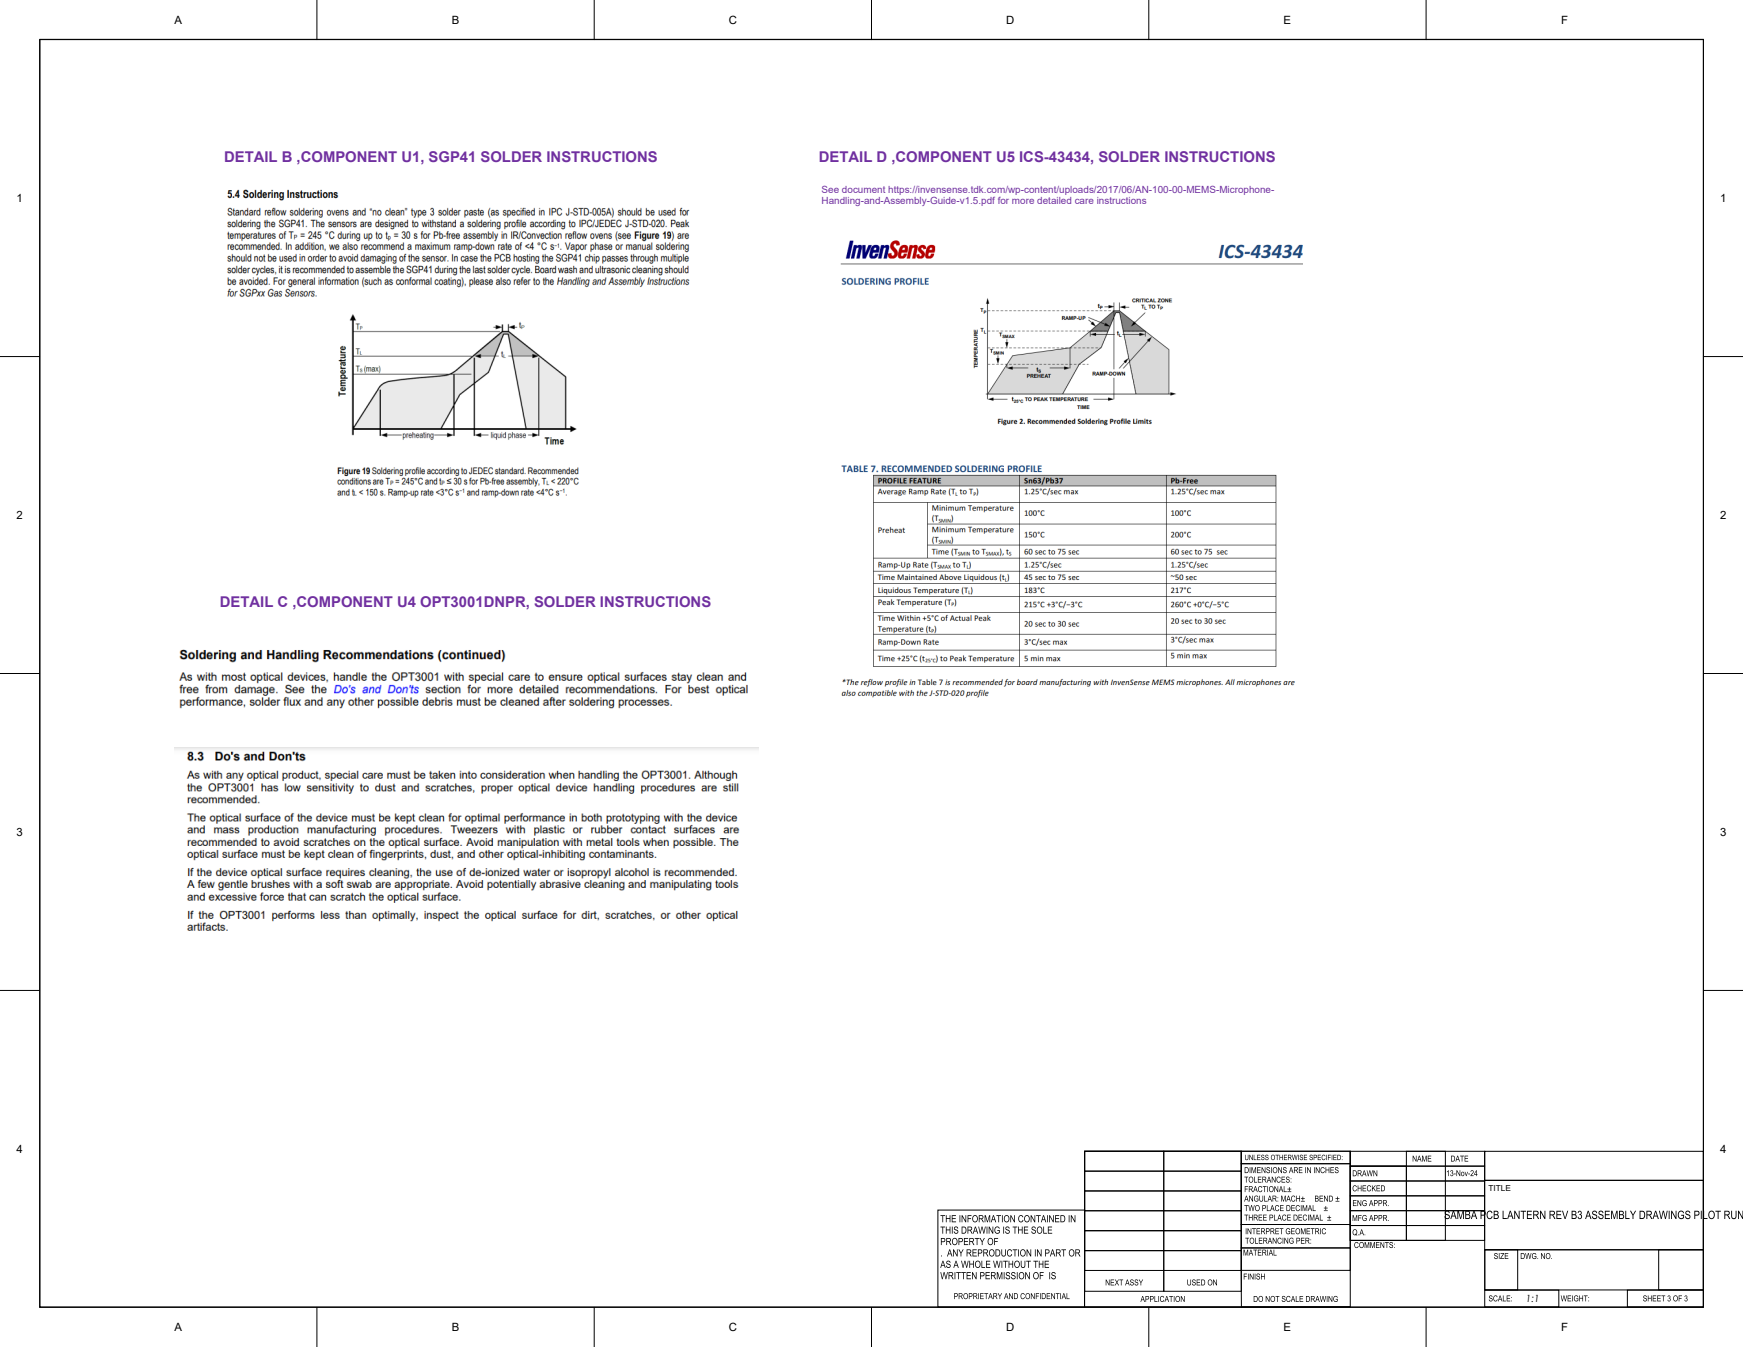
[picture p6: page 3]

DETAIL B ,COMPONENT U1, SGP41 SOLDER INSTRUCTIONS

DETAIL D ,COMPONENT U5 ICS-43434, SOLDER INSTRUCTIONS

See document https://invensense.tdk.com/wp-content/uploads/2017/06/AN-100-00-MEMS-Microphone-
Handling-and-Assembly-Guide-v1.5.pdf for more detailed care instructions

DETAIL C ,COMPONENT U4 OPT3001DNPR, SOLDER INSTRUCTIONS

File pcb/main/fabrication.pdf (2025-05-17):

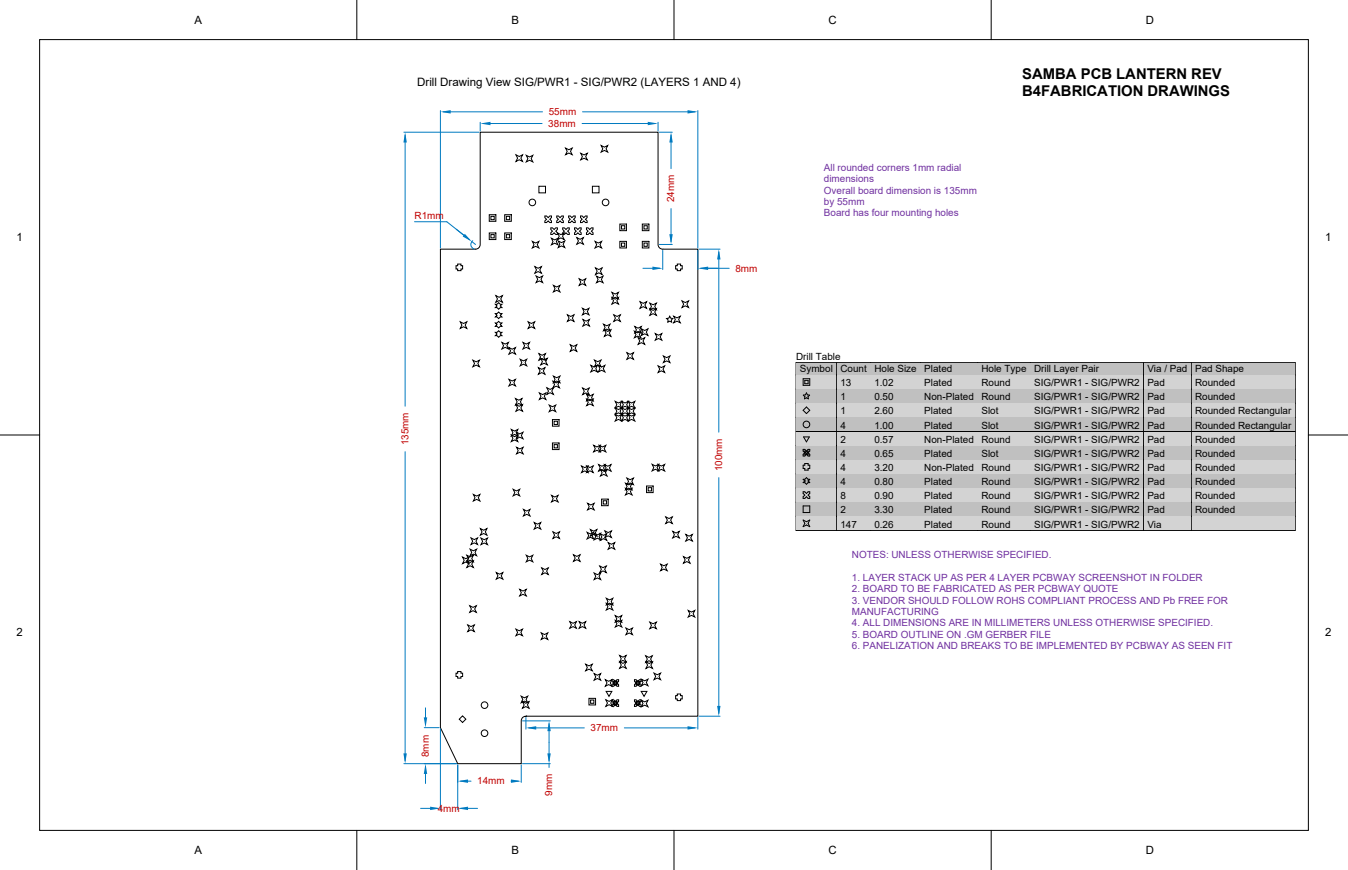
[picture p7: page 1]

SAMBA PCB LANTERN REV
B4FABRICATION DRAWINGS

Drill Drawing View SIG/PWR1 - SIG/PWR2 (LAYERS 1 AND 4)

All rounded corners 1mm radial
dimensions
Overall board dimension is 135mm
Board has four mounting holes

Symbol | Count | Hole Size | Plated | Hole Type | Drill Layer Pair | Via / Pad | Pad Shape

13 | 1.02 | Plated | Round | SIG/PWR1 - SIG/PWR2 | Pad | Rounded
1 | 0.50 | Non-Plated | Round | SIG/PWR1 - SIG/PWR2 | Pad | Rounded
1 | 2.60 | Plated | Slot | SIG/PWR1 - SIG/PWR2 | Pad | Rounded Rectangular
4 | 1.00 | Plated | Slot | SIG/PWR1 - SIG/PWR2 | Pad | Rounded Rectangular
2 | 0.57 | Non-Plated | Round | SIG/PWR1 - SIG/PWR2 | Pad | Rounded
4 | 0.65 | Plated | Slot | SIG/PWR1 - SIG/PWR2 | Pad | Rounded
4 | 3.20 | Non-Plated | Round | SIG/PWR1 - SIG/PWR2 | Pad | Rounded
4 | 0.80 | Plated | Round | SIG/PWR1 - SIG/PWR2 | Pad | Rounded
8 | 0.90 | Plated | Round | SIG/PWR1 - SIG/PWR2 | Pad | Rounded
2 | 3.30 | Plated | Round | SIG/PWR1 - SIG/PWR2 | Pad | Rounded
147 | 0.26 | Plated | Round | SIG/PWR1 - SIG/PWR2 | Via

NOTES: UNLESS OTHERWISE SPECIFIED.

1. LAYER STACK UP AS PER 4 LAYER PCBWAY SCREENSHOT IN FOLDER
2. BOARD TO BE FABRICATED AS PER PCBWAY QUOTE
3. VENDOR SHOULD FOLLOW ROHS COMPLIANT PROCESS AND Pb FREE FOR
MANUFACTURING
4. ALL DIMENSIONS ARE IN MILLIMETERS UNLESS OTHERWISE SPECIFIED.
5. BOARD OUTLINE ON .GM GERBER FILE
6. PANELIZATION AND BREAKS TO BE IMPLEMENTED BY PCBWAY AS SEEN FIT

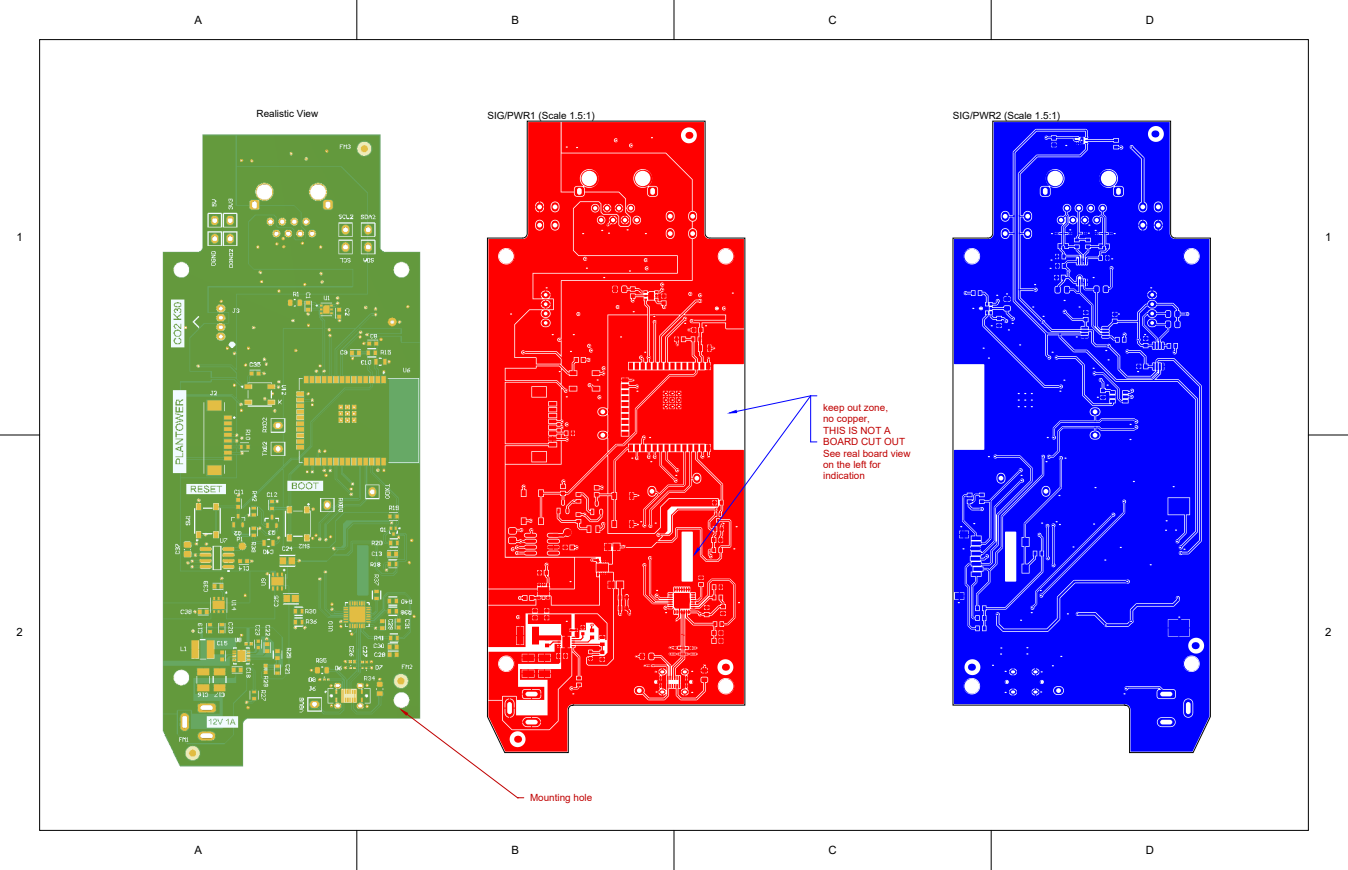
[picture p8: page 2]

keep out zone,
no copper,
THIS IS NOT A
BOARD CUT OUT
See real board view
on the left for
indication

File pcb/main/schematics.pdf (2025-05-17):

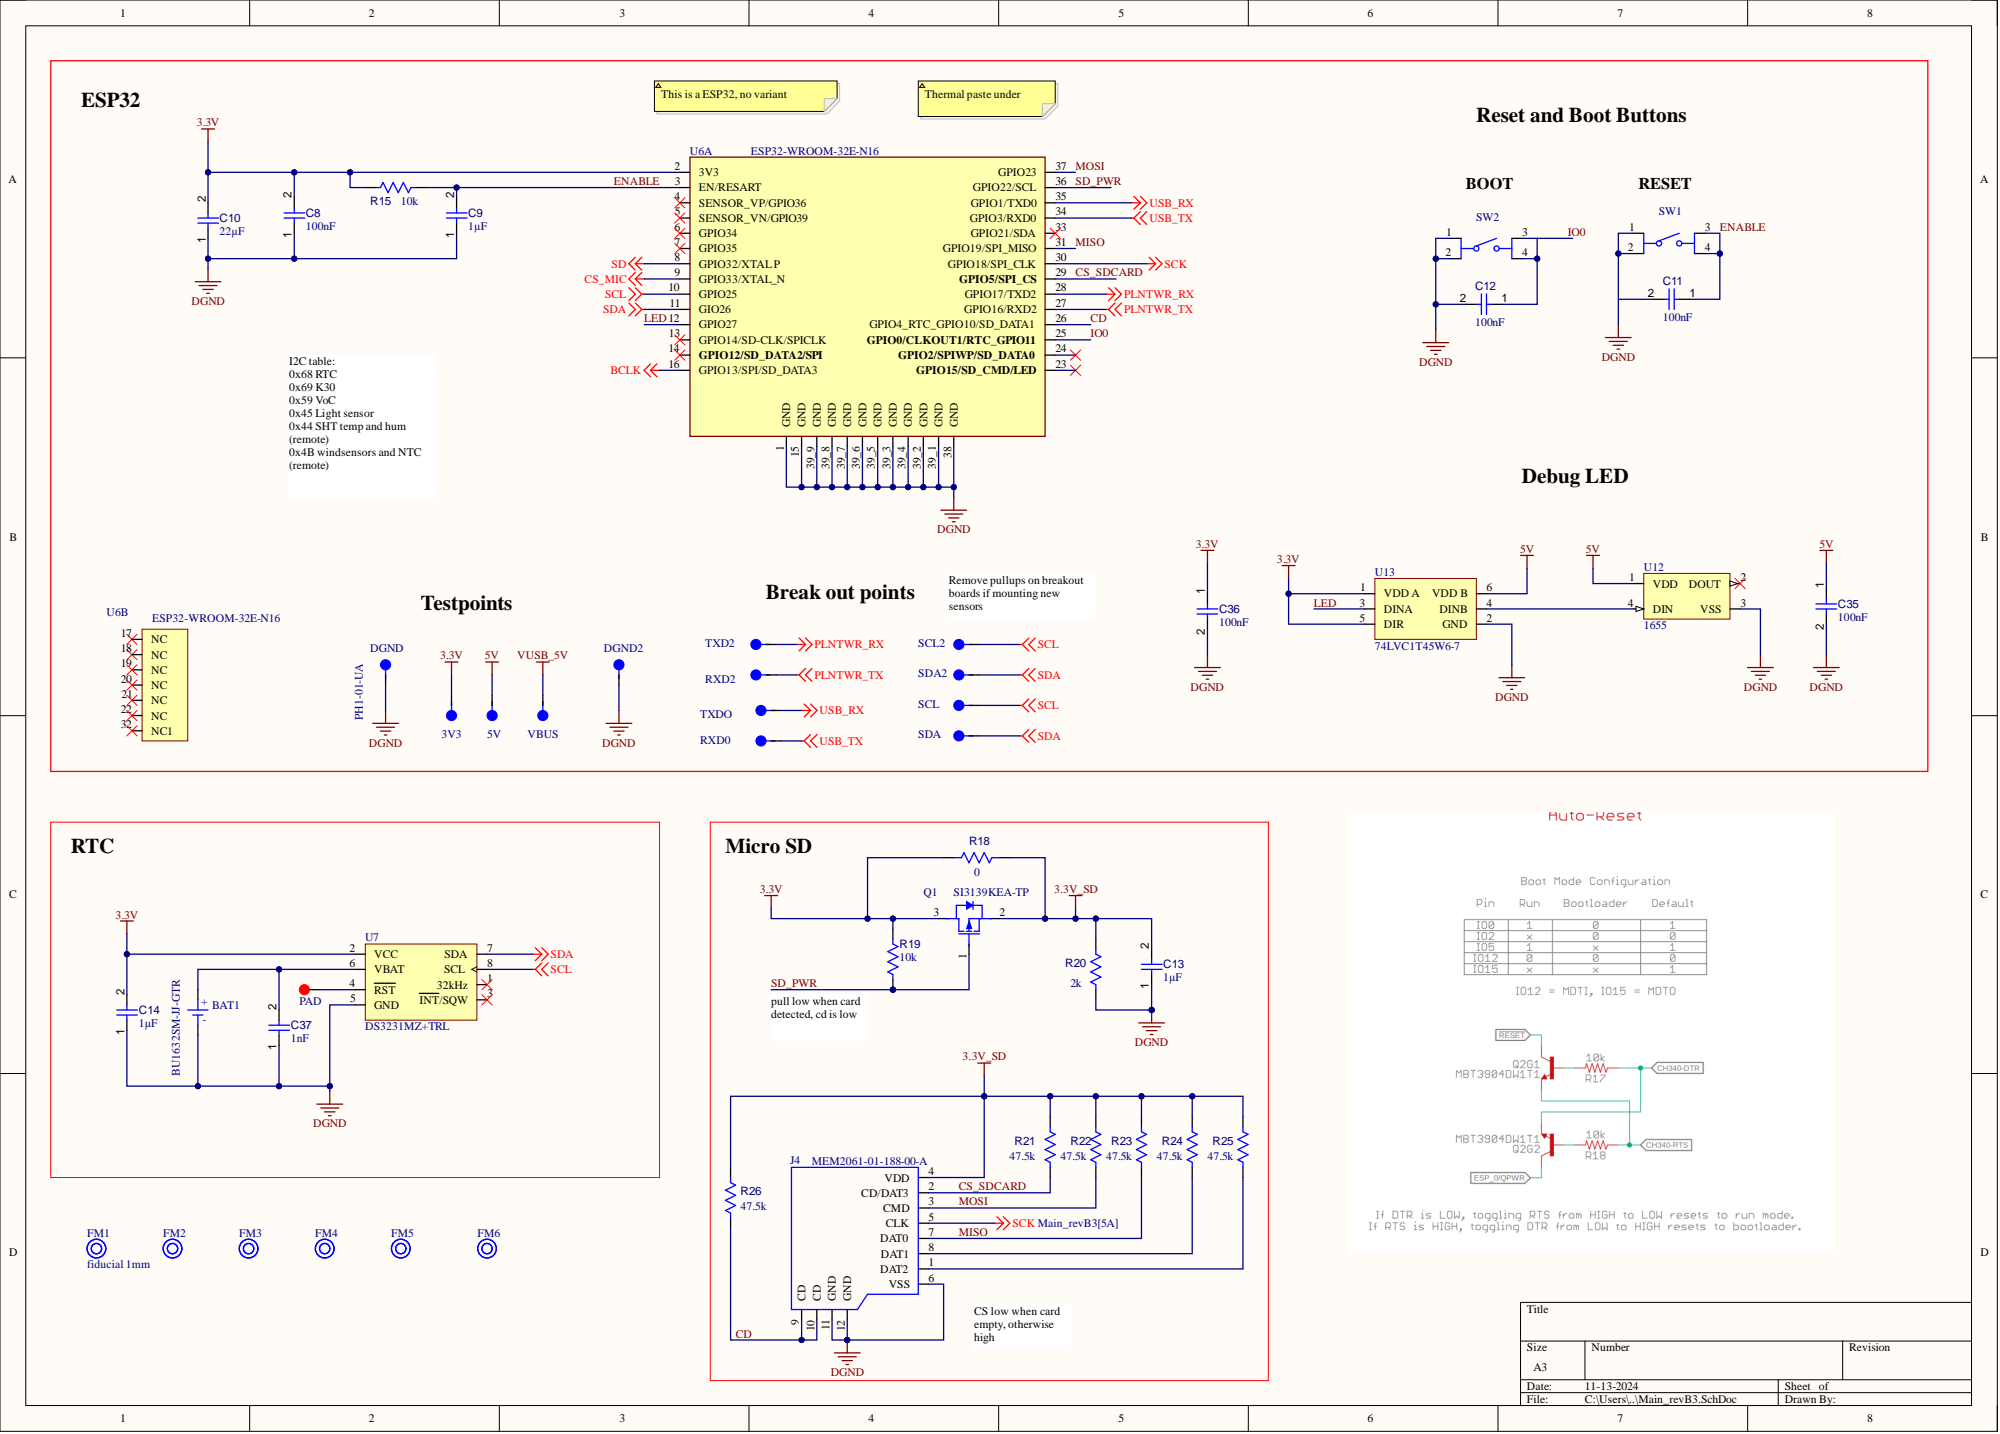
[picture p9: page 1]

Reset and Boot Buttons

GND 39_5 GND 39_6 GND 39_7 GND 39_8 GND 39_9

Remove pullups on breakout
boards if mounting new

sensors Break out points

SD_PWR
pull low when card
detected, cd is low

CS low when card
empty, otherwise
high

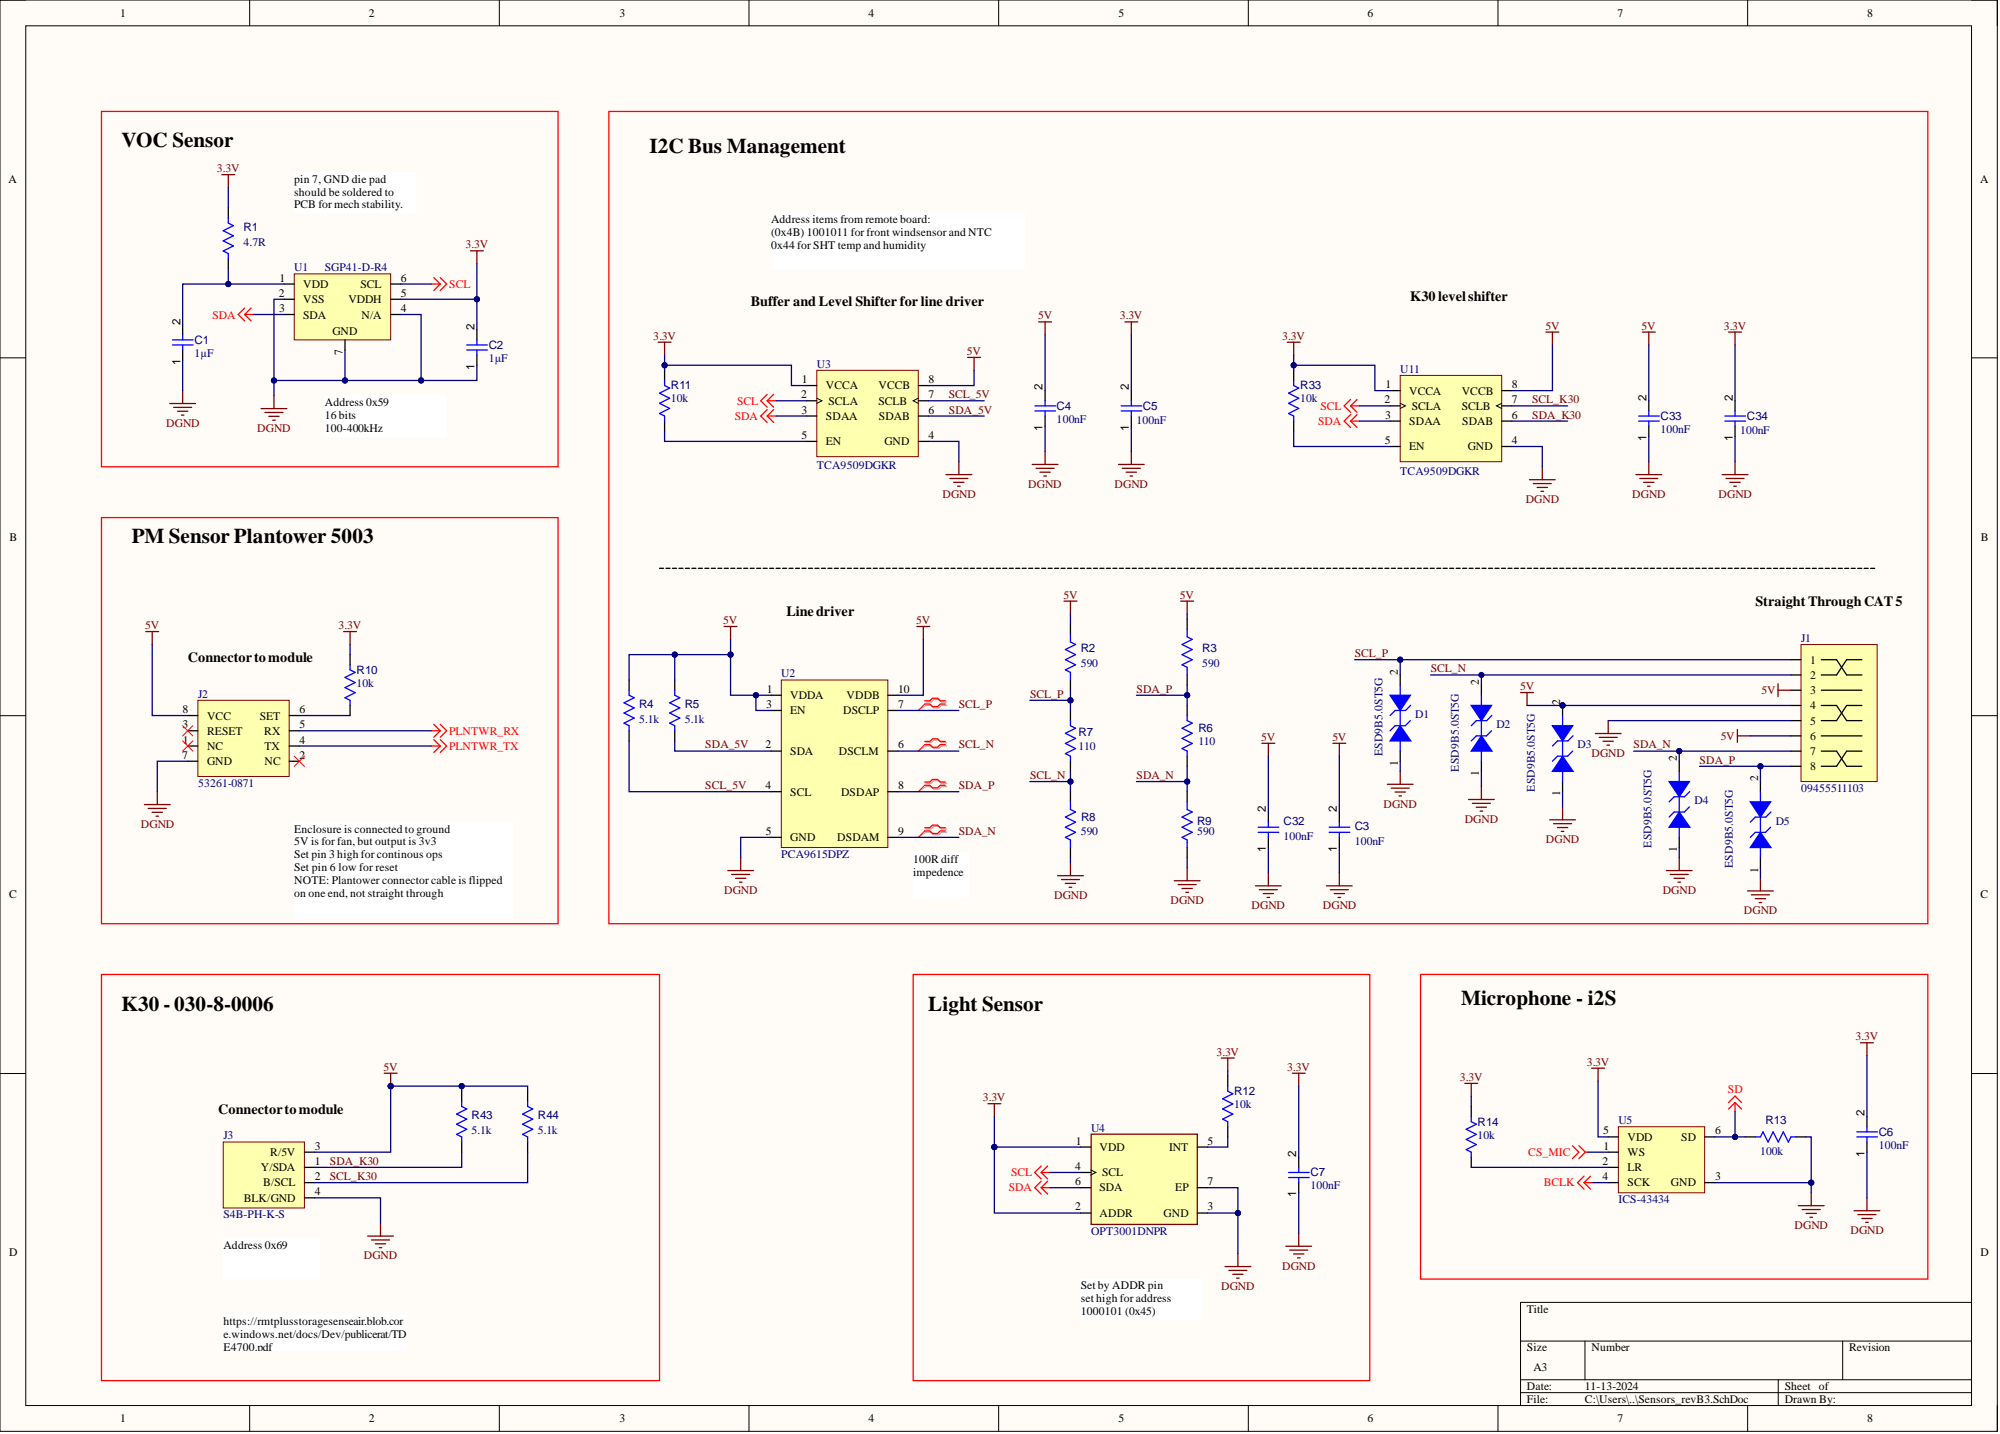
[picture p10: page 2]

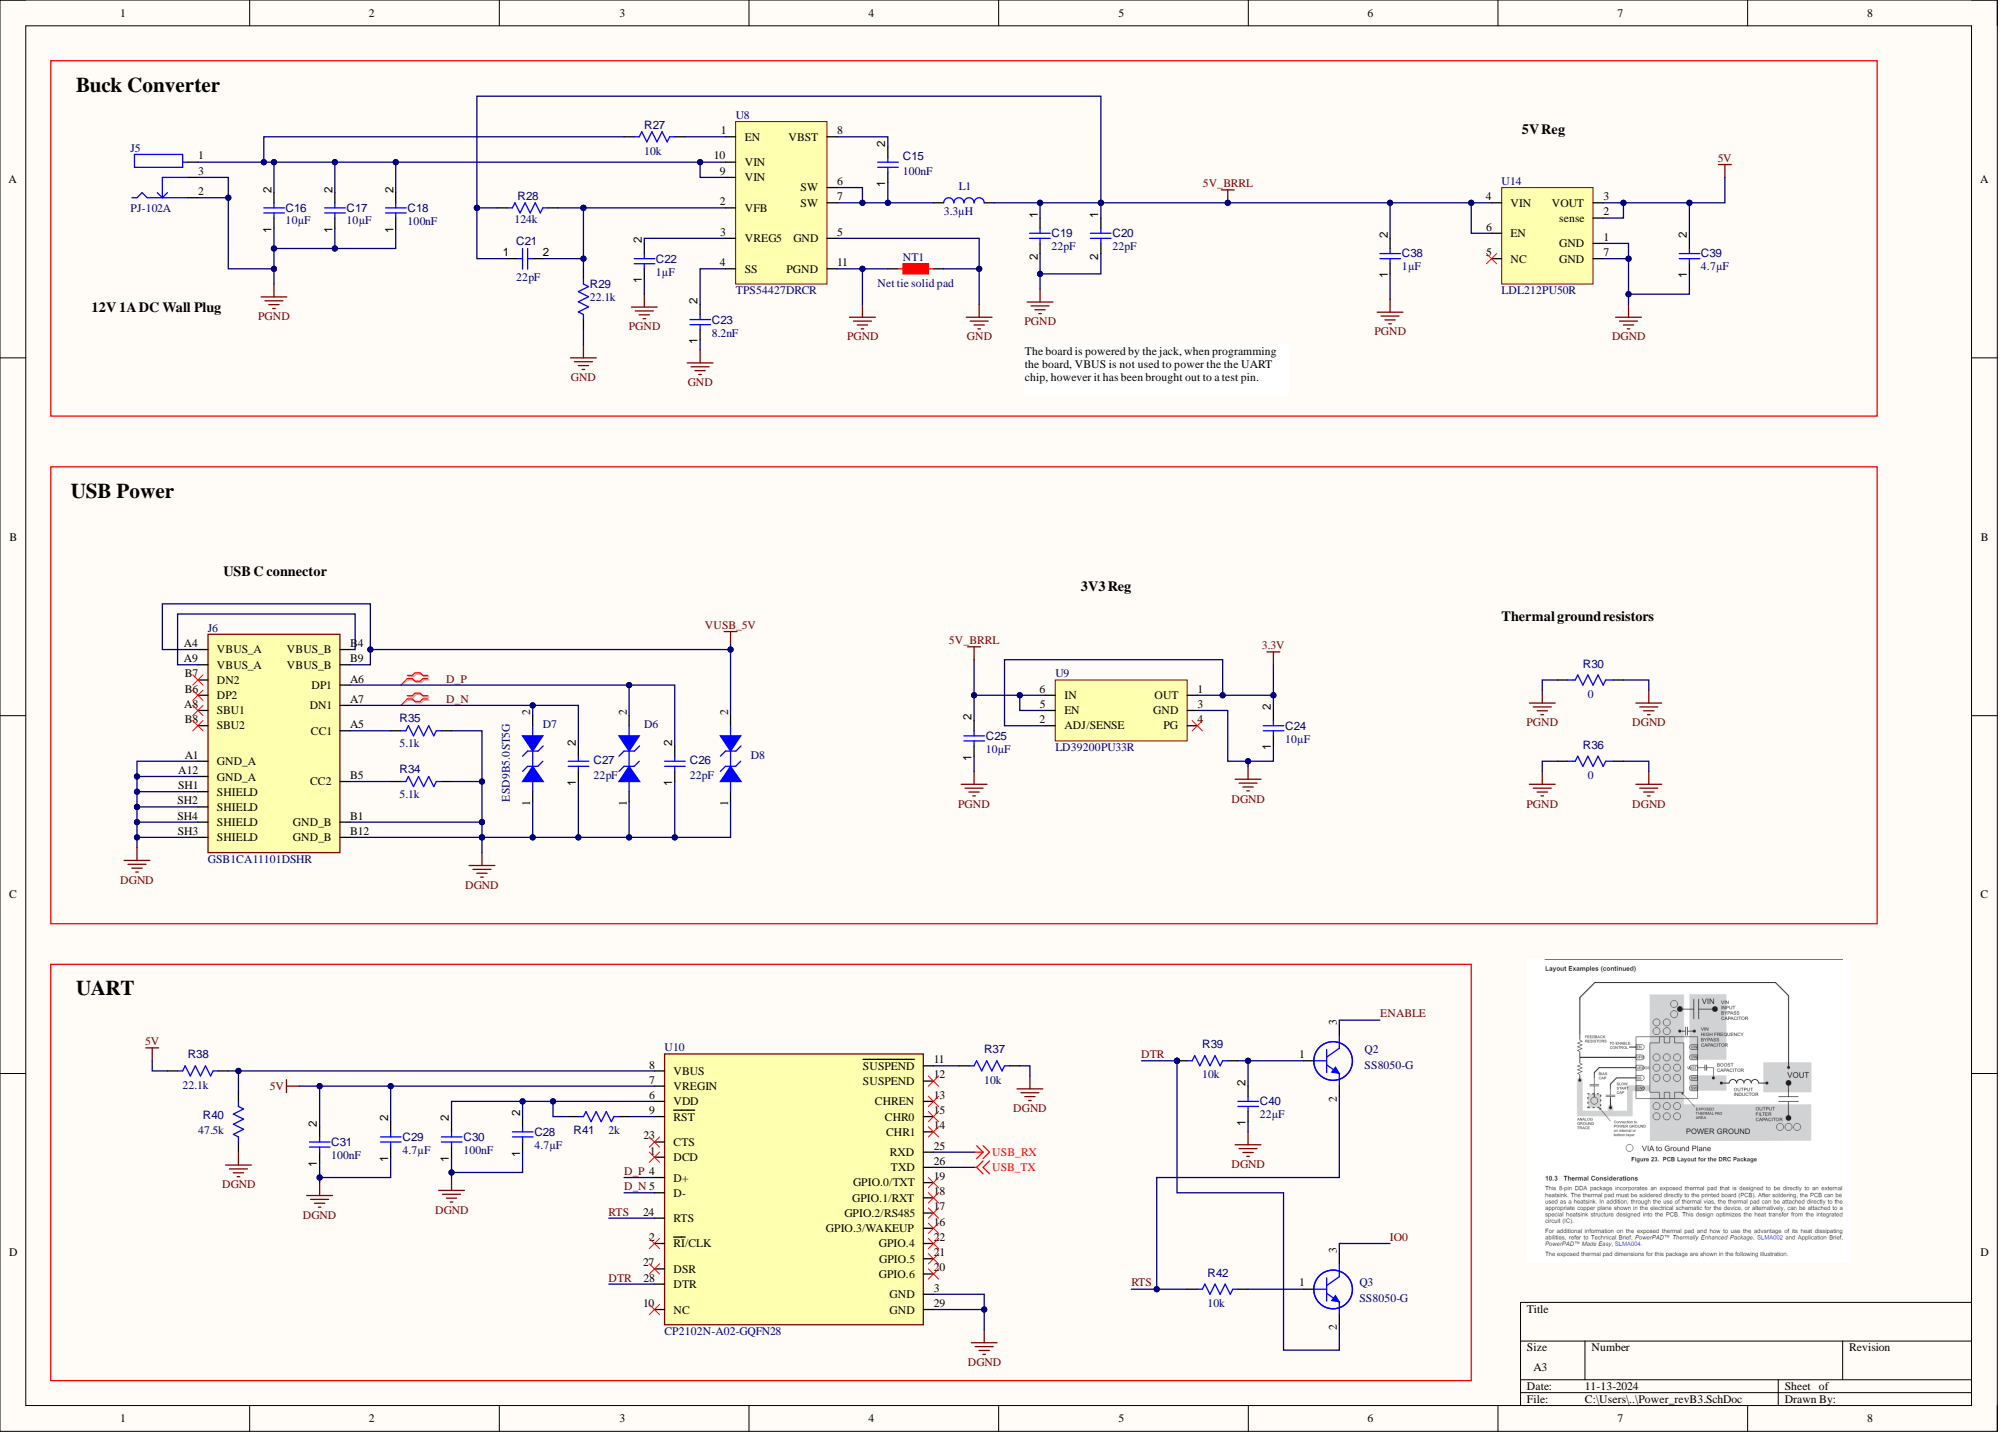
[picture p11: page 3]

VREG5 3

Net tie solid pad

The board is powered by the jack, when programming
the board, VBUS is not used to power the the UART
chip, however it has been brought out to a test pin.

GND_A A12
SHIELD SH1
SHIELD SH2

VDD 6

C40 DGND

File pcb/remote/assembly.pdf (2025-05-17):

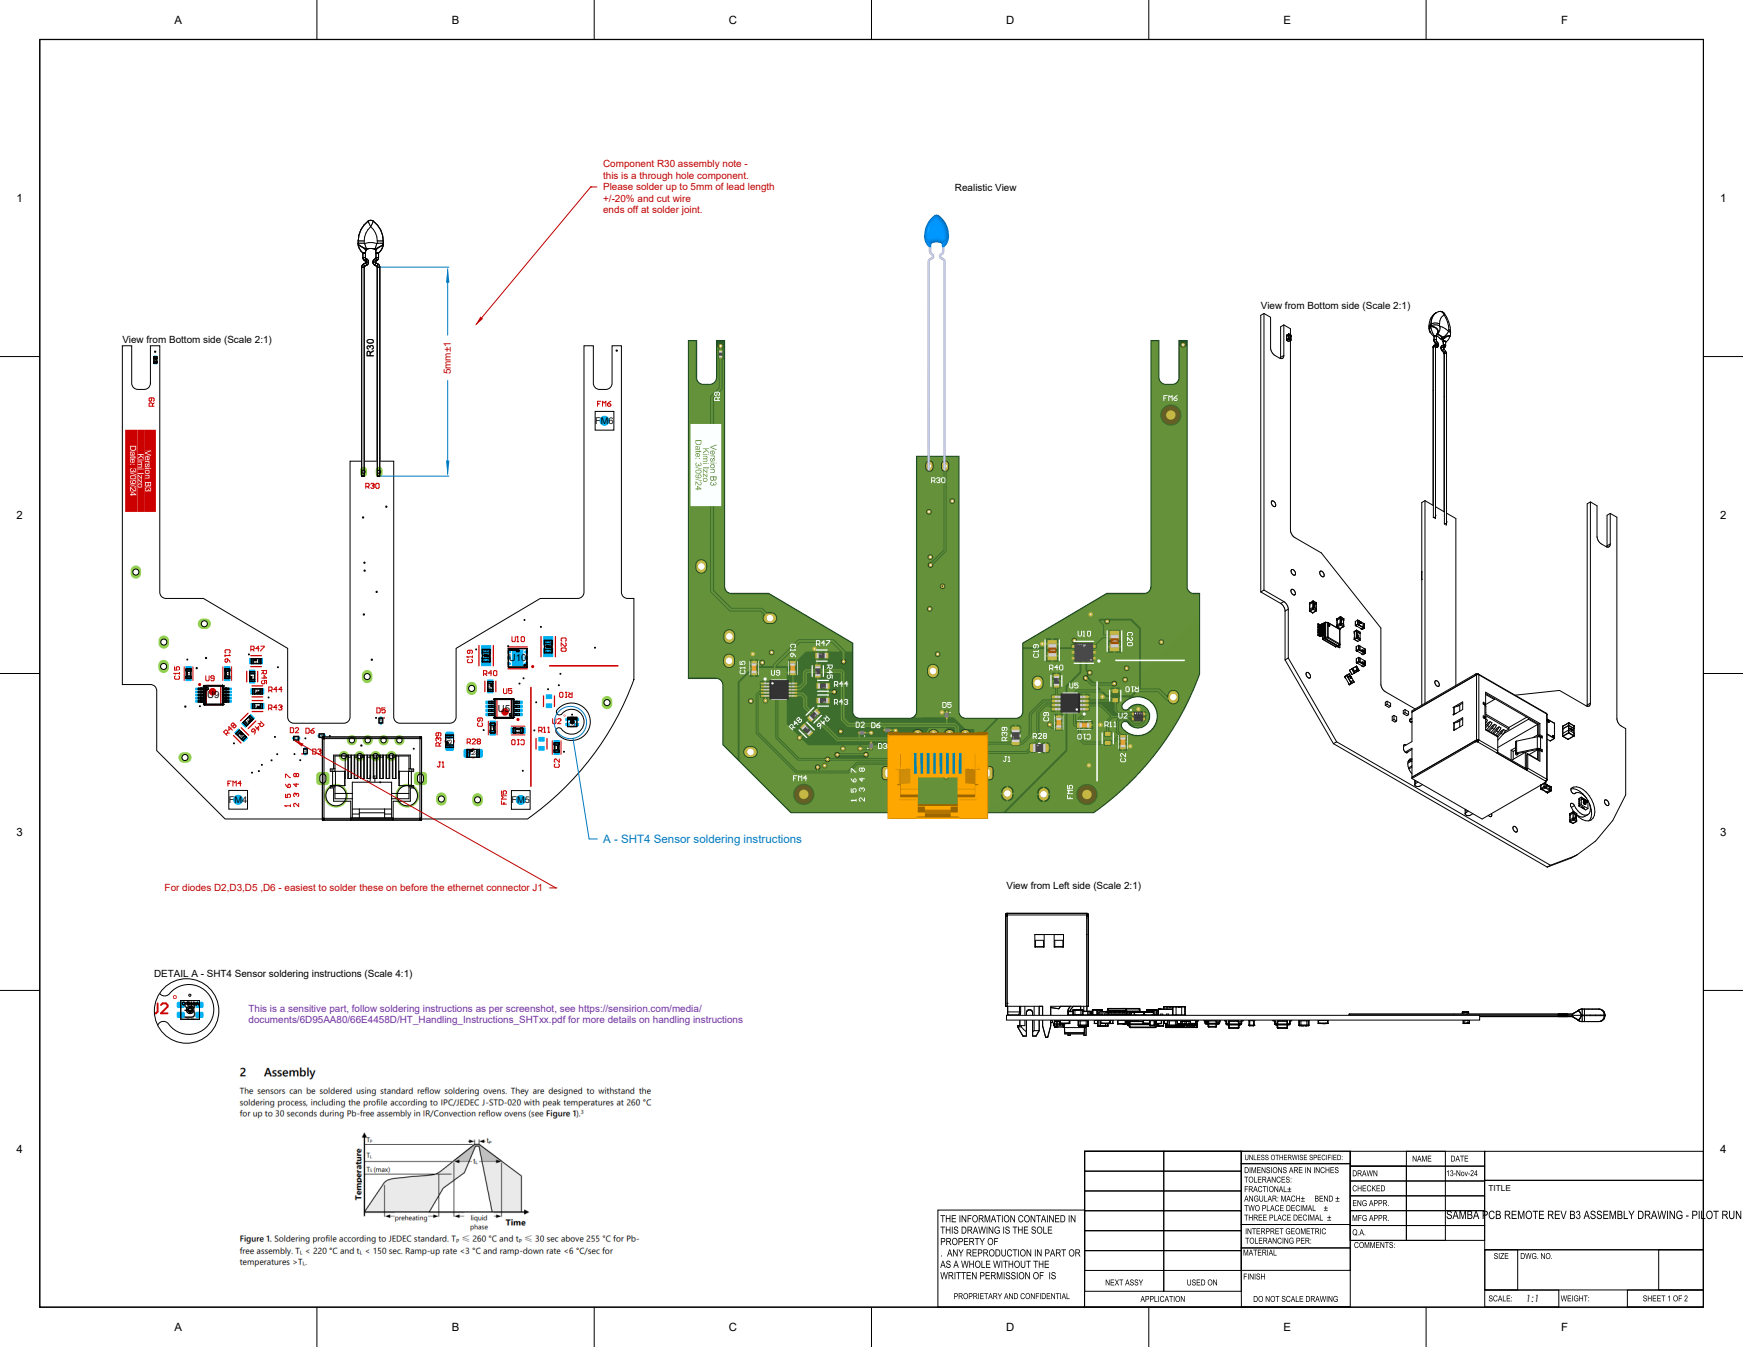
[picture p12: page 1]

Component R30 assembly note -
this is a through hole component.
Please solder up to 5mm of lead length
+/-20% and cut wire
ends off at solder joint.

View from Bottom side (Scale 2:1)

For diodes D2,D3,D5 ,D6 - easiest to solder these on before the ethernet connector J1

View from Left side (Scale 2:1)

DETAIL A - SHT4 Sensor soldering instructions (Scale 4:1)

This is a sensitive part, follow soldering instructions as per screenshot, see https://sensirion.com/media/
documents/6D95AA80/66E4458D/HT_Handling_Instructions_SHTxx.pdf for more details on handling instructions


View from Top side (Scale 2:1)

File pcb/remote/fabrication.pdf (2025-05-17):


SAMBA PCB REMOTE REV B3 FAB DRAWING - PILOT
RUN 13 OCTOBER 2024

Drill Drawing View (Scale 1.7:1)

Overall board dimensions are 82mm

All rounded corners are R1mm
All unique dimensions marked

Board cut out shape, 1mm thick
arc, 2.5mm radius. Tolerance on
1mm thickness, +/- 10%

NOTES: UNLESS OTHERWISE SPECIFIED.

Symbol | Count | Hole Size | Plated | Hole Type | Drill Layer Pair | Via / Pad | Pad Shape

35 | 0.200mm | Plated | Round | SIG/PWR1 - SIG/PWR2 | Via
13 | 0.255mm | Plated | Round | SIG/PWR1 - SIG/PWR2 | Via
2 | 0.550mm | Plated | Round | SIG/PWR1 - SIG/PWR2 | Pad | Rounded
8 | 0.900mm | Plated | Round | SIG/PWR1 - SIG/PWR2 | Pad | Rounded
2 | 1.000mm | Plated | Slot | SIG/PWR1 - SIG/PWR2 | Pad | Rounded Rectangular
10 | 1.020mm | Plated | Round | SIG/PWR1 - SIG/PWR2 | Pad | Rounded
2 | 3.300mm | Plated | Round | SIG/PWR1 - SIG/PWR2 | Pad | Rounded
72 Total

1. LAYER STACK UP AS PER 4 LAYER PCBWAY SCREENSHOT IN FOLDER
2. BOARD TO BE FABRICATED AS PER PCBWAY QUOTE
3. VENDOR SHOULD FOLLOW ROHS COMPLIANT PROCESS AND Pb FREE FOR MANUFACTURING
4. ALL DIMENSIONS ARE IN MILLIMETERS UNLESS OTHERWISE SPECIFIED.
5. BOARD OUTLINE ON .GM GERBER FILE
6. SEE DETAIL A FOR TOLERANCE SPEC ON BOARD CUT OUT
7. PANELIZATION AND BREAKS TO BE IMPLEMENTED BY PCBWAY AS SEEN FIT


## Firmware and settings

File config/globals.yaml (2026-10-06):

# SAMBA v2 FIRMWARE
# Create global parameters and restore from flash
# written by Thomas Parkinson, June 2025


# Define global variables that persist after reset
# https://esphome.io/components/globals.html
globals:
  - id: building_tag
    type: std::string
    max_restore_data_length: 24
    restore_value: yes
    initial_value: '"building"'

  - id: level_tag
    type: std::string
    max_restore_data_length: 24
    restore_value: yes
    initial_value: '"level"'

  - id: zone_tag
    type: std::string
    max_restore_data_length: 24
    restore_value: yes
    initial_value: '"zone"'

  - id: updates_enable
    type: bool
    restore_value: yes
    initial_value: 'true'

  - id: influx_enable
    type: bool
    restore_value: yes
    initial_value: 'true'

  - id: sd_enable
    type: bool
    restore_value: yes
    initial_value: 'true'

  - id: led_enable
    type: bool
    restore_value: yes
    initial_value: 'true'

  # InfluxDB token provisioned over the native API; empty = no upload
  # v2 tokens are 88 characters, which max_restore_data_length must cover
  - id: influx_token
    type: std::string
    max_restore_data_length: 88
    restore_value: yes
    initial_value: '""'

  # OTA password provisioned over the native API; empty = none
  - id: ota_password
    type: std::string
    max_restore_data_length: 64
    restore_value: yes
    initial_value: '""'

  # SD file server pairing password provisioned over the native API; empty = listener off
  - id: fileserver_password
    type: std::string
    max_restore_data_length: 32
    restore_value: yes
    initial_value: '""'

  # CO2 calibration (y = mx + b)
  - id: calibration_co2_m
    type: double
    restore_value: yes
    initial_value: '1.0'
  - id: calibration_co2_b
    type: double
    restore_value: yes
    initial_value: '20.0'

  # Illuminance calibration; the defaults below are samba_calibration's fleet medians (2026-10-05)
  - id: calibration_lux_m
    type: double
    restore_value: yes
    initial_value: '6.669'
  - id: calibration_lux_b
    type: double
    restore_value: yes
    initial_value: '0.0'

  # Air temperature calibration: the median slope, offset reading 22 C at the median unit's raw 22 C
  - id: calibration_ta_m1
    type: double
    restore_value: yes
    initial_value: '1.034'
  - id: calibration_ta_b
    type: double
    restore_value: yes
    initial_value: '-6.78'

  # Globe temperature calibration, as Ta
  - id: calibration_tg_m
    type: double
    restore_value: yes
    initial_value: '1.010'
  - id: calibration_tg_b
    type: double
    restore_value: yes
    initial_value: '-3.25'

  # Anemometer calibration, K in v = exp(K + C1*V + G*(Ta - 22)) (config/airspeed.yaml)
  # New ids on purpose: NVS keys hash the id, so no older air speed blob is read as these
  # Each tip's median under exp2 (14 units, 2026-10-05): as2 sits about 0.25 below as1
  - id: calibration_as1_k
    type: double
    restore_value: yes
    initial_value: '-6.559'
  - id: calibration_as2_k
    type: double
    restore_value: yes
    initial_value: '-6.809'

# Define flash write interval
# https://esphome.io/components/esphome.html#preferences-component
preferences:
  flash_write_interval: 10min

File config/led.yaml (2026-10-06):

# SAMBA v2 FIRMWARE
# configure status LED and ligh effects
# https://esphome.io/components/light/esp32_rmt_led_strip.html
# written by Thomas Parkinson, May 2024


# Define LED component
light:
  - platform: esp32_rmt_led_strip
    id: samba_led
    channel_colors: GRB
    pin: GPIO27
    num_leds: 1
    rmt_symbols: 64
    chipset: ws2812

    # Linear: at the default 2.8, anything under ~12% brightness quantises to zero
    gamma_correct: 1.0

    # Dim for a dark office; alarms floor at 4% so amber stays amber, identify stays bright
    # Define LED effects
    effects:
      # Used for all sensor WARNING states
      - pulse:
          name: "pulse_slow"
          transition_length: 2s
          update_interval: 3s
          max_brightness: 0.04
      - strobe:
          name: "strobe_g"
          colors:
            - state: true
              brightness: 3%
              red: 0%
              green: 100%
              blue: 0%
              duration: 250ms
            - state: false
              duration: 750ms
      - strobe:
          name: "strobe_id"
          colors:
            - state: true
              brightness: 25%
              red: 0%
              green: 50%
              blue: 50%
              duration: 250ms
            - state: false
              duration: 250ms

# Master switch for every status indication; Identify SAMBA still blinks
switch:
  - platform: template
    name: "Status LED"
    id: switch_led
    icon: mdi:led-on
    entity_category: "config"
    restore_mode: DISABLED
    lambda: |-
      return id(led_enable);
    turn_on_action:
      # -1 makes the arbiter re-apply any current alarm on its next tick
      - lambda: |-
          id(led_enable) = true;
          id(led_alarm) = -1;
    turn_off_action:
      - lambda: |-
          id(led_enable) = false;
          id(led_alarm) = 0;
      - light.turn_off:
          id: samba_led

# Alarm indication
globals:
  # -1 until the arbiter has run once, so its first tick always applies a state
  - id: led_alarm
    type: int
    restore_value: no
    initial_value: '-1'
# Latches the boot guard below, so the 49.7-day millis() rollover cannot re-engage it.
  - id: led_armed
    type: bool
    restore_value: no
    initial_value: 'false'

interval:
  - interval: 10s
    then:
      - lambda: |-
          // Leave the boot strobe alone; latched against the millis() rollover
          if (!id(led_armed)) {
            if (millis() < 120000)
              return;
            id(led_armed) = true;
          }

          int want = 0;
          if (!id(led_enable)) {
            want = 0;                             // Status LED switch off: stay dark
          } else if (id(ads_error_detected).state) {
            want = 6;                             // amber solid
          } else if (id(k30_error_count) >= 4) {
            want = 5;                             // blue solid
          } else if (id(sgp_error_count) >= 6) {
            want = 4;                             // magenta solid
          } else if (id(ads_error_warning).state) {
            want = 3;                             // amber pulse
          } else if (id(k30_error_count) >= 3) {
            want = 2;                             // blue pulse
          } else if (id(sgp_error_count) >= 4) {
            want = 1;                             // magenta pulse
          }

          // Only on a change; re-applying every tick would restart the pulse
          const bool clobbered = (want != 0) && !id(samba_led).remote_values.is_on();
          if (want == id(led_alarm) && !clobbered)
            return;
          id(led_alarm) = want;

          if (want == 0) {
            id(samba_led).turn_off().perform();
            return;
          }

          auto call = id(samba_led).turn_on();
          switch (want) {
            case 6:
            case 3:
              call.set_rgb(1.0f, 0.5f, 0.0f);     // amber - ADS1115 (globe temp, air speed)
              break;
            case 5:
            case 2:
              call.set_rgb(0.0f, 0.0f, 1.0f);     // blue - K30 (CO2)
              break;
            default:
              call.set_rgb(1.0f, 0.0f, 1.0f);     // magenta - SGP4x (VOC, NOx)
              break;
          }
          if (want >= 4) {
            call.set_effect("none");
            call.set_brightness(0.04f);
          } else {
            // The effect drives brightness itself, so setting it here would be overridden
            call.set_effect("pulse_slow");
          }
          call.perform();

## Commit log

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2025-06-28 replace substitutions with globals
    [airspeed.yaml]
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2025-07-13 revert back to globals for influx
    [globals.yaml]
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2025-07-15 proper error handling for k30 sensor
    [senseair_i2c.cpp]
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2025-07-16 use power function with temp correction for air speed
    [airspeed.yaml, globals.yaml]
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2025-08-16 workaround esp-idf bug by removing global arrays
    [airspeed.yaml, globals.yaml]
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2025-10-01 remount after 3 failed writes
    [sd_spi_card.cpp, sd_spi_card.h]
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2025-10-03 retry mount after 2 failed writes
    [sd_spi_card.h]
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2025-10-06 fix checksums for diagnostic reads
    [senseair_i2c.cpp]
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2026-01-19 remove fixed ta offset
    [airspeed.yaml]
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2026-01-20 reduce sample window for i2c errors
    [airspeed.yaml]
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2026-03-16 include error code in logs
    [sd_spi_card.cpp]
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2026-08-19 release v1.99.98: fix unrecoverable safe mode boot loop
    Entering safe mode permanently bricked a device, needing a USB reflash.
    safe_mode calls App.setup() and on_safe_mode from inside
    should_enter_safe_mode(), before ESPHome emits the deferred wiring
    statements that follow the safe-mode early return in the generated
    setup(). Components registered before that return but wired after it are
    therefore set up with null pointers, and clean_rtc() saves the boot
    counter without syncing - so the crash landed before the counter cleared
    and the loop sustained itself indefinitely.
    Four faults, all verified on hardware:
    - copy sensors spl_laeq/spl_la90/spl_la10 had a null source_
    (LoadProhibited, EXC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
2026-08-19 revert I2C bus to 50kHz and rebuild v1.99.98
    v1.99.97 raised the I2C bus from 50kHz to 100kHz alongside the CPU bump to
    240MHz. The unit that bricked this week logged 47 I2C hardware timeouts in
    a single boot, plus ADS1115 read timeouts driving the K30 watchdog into
    repeated reboots - which is what accumulated the safe-mode boot counter in
    the first place. 50kHz ran without these symptoms through v1.99.96, so
    revert it; CPU stays at 240MHz.
    Rebuilt v1.99.98 in place rather than cutting a new version: the GitHub
    release is still a draft and no device has applied 1.99.98 yet, since
    fw_check only flashes on the Monday 04:00 UTC cron.
    md5 1868ef80... -> ff556bfa0df04fe46e4c2326975d9796
    Co-A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
2026-08-19 fix swapped pin assignments in CLAUDE.md pinout table
    Both rows had their pin roles reversed relative to config/esp32.yaml:
    I2C is scl GPIO25 / sda GPIO26, and UART PM is rx GPIO16 / tx GPIO17.
    Speed column is correct again now the bus is back to 50kHz.
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2026-08-19 give the K30 longer to answer before declaring failure
    The K30 acknowledges its address but NACKs the EEPROM read when polled
    before it has prepared a response. At read_delay_ms 40 it only just made
    it, often needing 4 of the 5 retries and sometimes exhausting them. That
    failed setup, which the watchdog counted as a sensor failure, and 4 of
    those rebooted the device - every ~2 minutes, faster than the 5 minute
    sample, so the unit reported nothing at all despite the other twelve
    sensors being healthy.
    Raise read_delay_ms to 80 and max_retries to 10. Verified on hardware
    across 8 boots plus 7 minutes undisturbed: no reboots, no crashes, and a
    completed sample cycle written to SD. Setup still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
2026-08-20 Require ESPHome 2026.8.0 and adopt channel_colors
    2026.8.0 deprecates rgb_order on esp32_rmt_led_strip in favour of the
    unified channel_colors key (removal in 2027.3.0).
    channel_colors does not exist before 2026.8.0, so min_version is raised
    to match. 2026.7.x would otherwise fail with a confusing schema error
    instead of a clear version error.
    [led.yaml]
2026-08-20 Fix printf format specifiers for uint32_t arguments
    uint32_t is long unsigned int on ESP32, so %u triggered -Wformat at
    eight call sites. Switched to the PRIu32/PRIX32 macros (ESPHome core's
    convention) and added <cinttypes>; the ota.yaml lambda casts instead,
    which reads better than escaping the macro inside YAML.
    Correctness and portability only. Both types are 32-bit with identical
    varargs promotion on this ABI, so codegen and output are unchanged. All
    five senseair_i2c sites are in setup/diagnostics paths, not the 30s
    measurement path, and are runtime-suppressed by senseair_i2c: ERROR.
    [senseair_i2c.cpp]
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2026-08-25 Harden InfluxDB uploads and surface dead sensors
    Rewrite the influxdb component around ESPHome's http_request client so the
    POST runs under its socket timeout and task-watchdog handling instead of a
    hand-rolled esp_http_client that could block the loop task for 12 s and
    trip the 5 s watchdog whenever the Influx host was unreachable.
    - Sensors are declared as {id, measurement, field} and resolved at codegen,
    so a typo is a config error rather than a silently dropped field.
    - Retries are status-aware: 5xx/429 retried from the scheduler with backoff
    (no delay() in the loop); other 4xx logged once with InfluxDB's error body.
    - One reused payload buffer; inf rejected; control characters stri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
    [tags.yaml]
2026-08-26 Rate-limit sensor watchdog restarts to once an hour
    A single dead sensor could take the whole device off the air. The ADS1115
    watchdog restarts after 5min of errors and the K30 after 4 failures (~2min),
    both faster than the 5min sample cycle, so a unit with one dead sensor rebooted
    forever and published nothing at all despite the other twelve being healthy.
    993db7e documented this for the K30; a bench unit reproduced it via the ADS1115
    path this week, rebooting every ~5min for hours without a single upload.
    Reporting a dead sensor is already handled: the raw read publishes NaN, so the
    field is absent in InfluxDB, nan on SD and unknown in Home Assistant. The
    restart was the only thing turnin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
2026-08-26 Recover a wedged I2C bus in place instead of rebooting
    A target that aborts mid-transaction holds the bus until it gives up on its own. The
    K30 is the usual culprit: ESP-IDF caps the clock-stretch timeout at 13ms in hardware, so
    a longer stretch aborts the transaction and leaves the bus wedged. Every ADS1115 read then
    times out, and the unit loses globe temperature and both air speed channels. ESPHome clocks
    a stuck target out exactly once, in IDFI2CBus::setup(), so the only way back was a reboot -
    and a reboot costs five minutes of every other sensor's data to fix a bus that nine clock
    pulses would have cleared.
    The i2c_recovery component (brought across unchanged from the i2c-bus-recovery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
2026-08-26 Adopt the esphome-conventions skill
    Salvaged from the i2c-bus-recovery branch, which is otherwise being deleted: it
    forked before 6ae97c9 and still carries frequency: 100kHz, so merging it would
    silently undo the 50kHz revert that commit made after 100kHz contributed to a
    bricked unit. Its i2c_recovery component has already been cherry-picked onto
    ads-soft-recovery, and its adc.yaml error-detection fix was reimplemented there.
    The skill was the only part worth keeping.
    Documents the conventions the components in components/ already follow -
    naming, field visibility, codegen shapes - plus the two references that matter
    most here: the heap-allocation policy and STL container selection for a d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
2026-08-26 Gate the ADS1115 restart on an hour-scale duty cycle
    Errors on this bus arrive in waves and then settle - the remote board hangs off
    several metres of Cat5 through an RJ45, so a loaded bus and a long lead make
    transient failures normal. A healthy unit measured ~18% of ADS1115 polls timing
    out at the IDF level over 34 minutes while still publishing globe temperature
    and air speed on all seven sample cycles. A restart must not react to one wave.
    ads_error_count already resets on any successful read, so it cannot fire on
    brief waves, and it keeps driving the LEDs and the soft recovery on a
    minutes-scale - reset_bus() is cheap and non-disruptive, so attempting it during
    a wave is wanted. Only t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
2026-08-26 Make the status LED legible at a glance and dim enough for an office
    Three problems. The palette had crowded four hues into one corner - cyan and
    blue for the K30, purple and magenta for the SGP4x - so the K30 warning was hard
    to tell from the white sample flash, and the SGP4x warning was hard to tell from
    its own error state. Severity was signalled by brightness, which is a relative
    cue: it needs a second LED alongside to compare against. And at 100% the error
    states are distracting in an occupied office.
    One rule now covers the scheme: colour identifies the subsystem, pulsing versus
    solid identifies severity. Amber is the ADS1115, blue the K30, magenta the
    SGP4x - three well-separated hue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
    [led.yaml]
2026-08-26 Keep retrying the K30 re-initialisation, and drop two unused LED effects
    reinitialize() was called only when the error count hit 1, so the K30 got
    exactly one recovery attempt per failure episode. If that attempt failed the
    sensor stayed dead until a restart cleared it. That was survivable while the
    restart came after 4 failures (~2 mins), but 3d19129 rate-limited restarts to
    once an hour to stop one dead sensor taking the whole unit off the air - which
    left up to an hour with no recovery attempted at all. A bench unit sat with a
    dead K30 for over an hour having tried to re-initialise exactly once. The two
    changes belong together and the first shipped without the second.
    Re-initialise immed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
    [led.yaml]
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2026-08-26 Drive the status LED from one place so alarms survive the sample heartbeat
    b0ebc2f built the pulse-vs-solid severity scheme on top of the existing
    arrangement, where each error path drove the LED itself from an edge-triggered
    action. That arrangement cannot hold an indication, for two reasons.
    sensor_sample ends in light.turn_off. Every 5min it wipes whatever the LED was
    showing, and because on_press fires only on the false->true edge, nothing ever
    re-fires to restore it. The K30 and SGP4x solid states happened to survive by
    accident: their interval re-performs the light call every 30s while the count
    stays above the threshold. Nothing else did. Both ADS1115 states and all three
    pulsing war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
    [led.yaml]
2026-08-26 Stop gamma correction swallowing the dim LED states
    b0ebc2f lowered the brightness of every LED state to suit an occupied office,
    without accounting for gamma correction. led.yaml never set gamma_correct, so it
    defaulted to 2.8, and it is applied on top of brightness: the byte reaching the
    WS2812 is roughly 255 * brightness^2.8. Anything below about 12% brightness
    quantises to zero.
    Three indications were therefore not dim, but off. The green boot strobe
    (10% x 50% green) and the white sample heartbeat (8%) both emitted a literal 0.
    The amber warning at 15% emitted red 1, green 0 - so it was 1/255 and the wrong
    hue, showing as dim red rather than amber. Only the 25% solid states survived,
    a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
    [led.yaml]
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2026-08-26 Hide the calibration numbers and MAC address from Home Assistant by default
    Mark the 18 calibration_* number entities and the MAC Address text sensor
    disabled_by_default so they do not appear on a Home Assistant device page,
    where a lay user could wreck a unit's calibration. Same pattern as the safe
    mode and factory reset entities. The native API still lists and accepts them,
    so samba_app is unaffected. Identify and Sample Now stay visible; they are
    harmless and useful for picking a unit out in a room.
    Verified on the bench unit: set_name_hash values unchanged, all 18 numbers
    publish, and list_entities reports disabled_by_default on exactly the 19
    entities intended.
    [calibration.yaml]
2026-08-26 Keep WiFi fresh in the upload and let the LED arbiter own the boot strobe
    Four fixes from an audit of the commits since v1.99.98.
    sample.yaml: wifi_signal polls on its own 300s cycle, independent of the RTC-aligned
    5-minute sample. The InfluxDB component only uploads a sensor that has published since
    the last upload, so a phase where two WiFi publishes land in one window leaves the next
    with none and drops `wifi` from device_status. Refresh it alongside sys_uptime.
    led.yaml: the arbiter's boot guard was meant to hand over at 120s, but with led_alarm
    starting at 0 the first tick past the guard matched `want` and returned early, so the
    green boot strobe survived until the first sample turned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
    [led.yaml]
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2026-08-27 Provision the InfluxDB token over the native API instead of compiling it in
    The token was a compile-time substitution, so it sat in every published
    firmware/*.bin. Now an influx_set_token api action stores it in a restored
    global (NVS, which OTA never rewrites) and hands it to the influxdb component,
    which prefers it over the compiled-in one. The compiled-in token stays as the
    fallback until the fleet is provisioned; a build with influx_token "" then
    carries no secret, and an unprovisioned unit skips uploads and reports so.
    Nothing publishes the token back: an "InfluxDB Token" text sensor carries its
    FNV-1 fingerprint (or "unset") and "InfluxDB Status" the outcome of the last
    upload attempt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
    [globals.yaml]
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2026-08-29 Provision the API key and OTA password at runtime, alongside the InfluxDB token
    The native API was plaintext and the esphome OTA password a shared secret in every
    published .bin. Both now follow the shape the InfluxDB token already has: set over the
    native API by samba deploy, one per building, kept in NVS which OTA never rewrites.
    The API key is ESPHome's own runtime Noise key (`encryption: {}`): an unkeyed unit
    accepts the all-zeros provisioning handshake or plaintext, saves the key a client sets,
    drops every client and is Noise-only from then on. Nothing about it is in the binary.
    The OTA password keeps `password: "${ota_password}"` as the compiled-in fallback and
    gains an ota_set_passwo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
    [globals.yaml]
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2026-09-02 Drop out air speed per channel when the ADS1115 stops reading
    A failed ADS1115 read publishes nothing, so as_1 and as_2 hold their last good values and
    samba_airspeed returns the same max() of two frozen numbers every sample.
    Guard each channel separately rather than the pair. max() of a live channel and a frozen one
    returns whichever is larger, so a single dead anemometer could keep winning the comparison and
    mask itself indefinitely; taking the survivor explicitly is both honest and more useful than
    dropping the measurand entirely. NaN only when both are stale.
    330000ms as elsewhere, which at the 2s poll rate is 165 consecutive failed reads - far more
    tolerant than the 6s staleness the L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
    [airspeed.yaml]
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2026-09-02 Latch the boot guards past the millis() rollover
    The LED arbiter and the SGP4x error counter each open with a bare millis() < N boot guard.
    millis() wraps every 49.7 days, so both re-engage after the rollover: the LED arbiter stops
    applying alarm states for two minutes and SGP4x error counting is skipped for 150 seconds, on
    a device that had been up for seven weeks and was working perfectly.
    Latch each behind a bool global instead, so the guard fires once per boot as intended.
    Only these two were affected. The k30 warmup guard is already safe because it is ANDed with
    k30_last_ok == 0, which cannot be true after a rollover, and every other use of millis() here
    is a difference between two ui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
    [led.yaml]
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2026-09-19 Tolerate bus_a transaction loss instead of latching on it
    The K30 implements I2C in software and holds SCL low for ~40ms while it measures
    (TDE4700 section 6.1, 3.7). The ESP32 timeout register is 20 bits of APB clock, so
    13ms is a hardware ceiling that ESPHome and ESP-IDF both clamp to. Any transaction
    on bus_a overlapping that window is therefore a guaranteed hardware timeout, whatever
    device it addresses, and no master-side recovery shortens it: a target holding SCL
    cannot be clocked free the way one holding SDA can, and an open-drain master cannot
    even raise SCL to form a STOP. Losing the occasional transaction here is structural.
    A component that responds by disabling itself is the bug.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
    [senseair_i2c.cpp]
2026-09-20 Condense the config comments to the project's register
    Comment-only across config/*.yaml: non-comment lines are byte-identical and
    `esphome config samba.yaml` passes. 234 lines removed for 92.
    YAML comments are one or two lines again, describing what a block does rather
    than reconstructing why it was written that way. The rationale they carried was
    almost entirely duplicated: influxdb.h already documents the per-sensor
    freshness and drop-out semantics, sd_file_server.h the password-gated listener,
    and CLAUDE.md the dropout guards, the clamp/NaN trap, the safe-mode rule, the
    timezone pin and the bus_a tolerance. Two facts had no home and moved to
    CLAUDE.md - that a flood of `Reading ADS1115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
    [calibration.yaml]
2026-09-23 Ship credentials without compiled-in fallbacks
    The InfluxDB token and the esphome OTA password now exist only as
    provisioned over the native API. influxdb loses its token: option and
    compiled-in branch outright rather than keeping token: "", so no build
    can carry one again; set_token_override becomes set_token, and
    dump_config reports provisioned or none. ota keeps password: "" so the
    auth path compiles, and clearing the provisioned password now leaves OTA
    unauthenticated instead of reverting to a compiled-in one.
    Also drops the Factory Restore switch (a wipe is a USB or lab operation)
    and the unused wifi, hotspot and enterprise substitutions with the
    commented networks and manual_ip blocks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
    [globals.yaml]
2026-09-23 Remove the 1.x shims from the calibration surface
    - The RH slope and offset entities and globals: the RH chain applies the
    vapour pressure correction and never read them.
    - disabled_by_default on the calibration numbers: the client reads them
    over the native API, and hiding them in Home Assistant bought nothing.
    - The on_client_connected coefficient dump; the client reads the
    entities, and the dump would otherwise have to track every rename.
    - SenseairI2CSensor::perform_calibration_command_, which had no caller.
    samba_calibration/firmware/components/senseair_i2c is refreshed to
    match on its v2 branch.
    [calibration.yaml]
2026-09-23 Replace the anemometer power law with King's law, values held
    Per anemometer, V^2 = (1 - k*Ta) * (A + B*v^n), solved for v in the
    airspeed.yaml filter lambda, with Ta falling back to 22 degC as before.
    New globals and entities, calibration_as{1,2}_king_{a,b,n,k} and
    "Anemometer {1,2} [A|B|n|k]": NVS keys hash the global id, so reusing
    the 1.x ids would load power-law values into King's coefficients on a
    unit reflashed from 1.x, and the new names cannot collide with the old
    ones on object_id. The [a] [b] [d0] [d1] entities and globals are gone;
    their NVS blobs are orphaned and read by nothing.
    The lambda returns NaN for an unusable coefficient set or 1 - k*Ta <= 0,
    0.02 m/s below the fitted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
    [calibration.yaml]
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2026-09-25 Erase the SD card over the native API: sd_erase for the deploy gate
    A returned unit's card holds its last deployment in plain text, and FAT
    deletion or a format only frees clusters. sd_spi_card.erase runs a
    whole-card SD ERASE (sdmmc_full_erase), then remounts with
    format_if_mount_failed; a card that refuses the erase is formatted
    instead and reports "formatted". Both run on their own FreeRTOS task,
    since an erase plus FAT32 format takes ~19 s, far past the loop
    watchdog; the card reads unmounted meanwhile, so the append and the
    file server leave it alone, and on_mount fires again at the end.
    config/sd.yaml adds the sd_erase action, which also resets sd_logfile
    so the fresh log gets its hea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
    [sd_spi_card.cpp, sd_spi_card.h]
2026-09-25 Replace King's law with the level-5 fleet air speed model
    v = exp(K + C1*V + G*(Ta - 22)), clamped to 0.02-1.0 m/s. C1 = 3.0043 /V and
    G = 0.2321 /C are fleet constants from samba_calibration's
    analysis/airspeed_fleet.R, compiled in as substitutions; K is the one
    per-tip coefficient, Anemometer 1 [K] and Anemometer 2 [K], default -6.165
    (the September batch's fleet median, TODO(v2) until confirmed).
    The Air Speed Model text sensor publishes the model id, exp1, at boot, so
    the client can refuse a K fitted under other constants. King's law goes
    outright: it is undefined above about 33 C with k free, and no unit held
    its coefficients.
    [calibration.yaml]
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2026-09-28 Retry SGP4x setup instead of losing VOC and NOx for the whole boot
    ESPHome's sgp4x marked itself failed for the whole boot on the first
    lost setup or self-test transaction, and on bus_a the K30 blocks enough
    of them that 2 of 7 bench boots had no VOC or NOx. The SGP4x never
    restarts the unit, so a field unit that lost that draw reported nothing
    until something else rebooted it.
    components/sgp4x is upstream 2026.9.0 plus retries: five attempts at
    each setup read and at the whole self-test, 100ms apart. A self-test
    reply reporting a pixel fault still fails at once. Re-running setup()
    from YAML is not a substitute, because the 1Hz sampler is registered
    before the self-test result and would dou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
    [sgp4x.h]
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2026-09-29 Dim the status LED and create the SD log at the first sample (#28)
    * Dim the status LED and create the SD log at the first sample
    The LED drives the WS2812 linearly, so even the "low" settings were glaring in a
    dark room: the heartbeat lit all three channels at 20/255 and a solid alarm at
    64/255. Heartbeat drops to 2%, alarms (solid and pulse peak) to 4% and the boot
    strobe to 3%. Alarms stop at 4% because amber is red plus half green and drifts
    to red below that. Identify keeps its brightness so a unit can be found in a rack.
    sd_create ran on time sync and on mount, so a unit in a boot loop left an empty
    log per boot, thousands a day, until the card's directory slowed the unit into
    a loop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
    [led.yaml, tags.yaml]
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2026-10-05 Air speed model exp2 (C1 2.9487, G 0.2745); Ta slope floor 0.8
    samba_calibration now references Ta to the tunnel channel's air, which is
    warmer than the room (R44). That shrinks Ta's span across a calibration by
    about 10 %, so G grew: exp1 (3.0043, 0.2321) failed 12 of 15 units on the
    corrected Ta, exp2 passes 14. The K default is exp2's fleet median, -6.576.
    Fitted Ta slopes now sit near 1.0 (0.989 on one unit), so cal_ta_m1's floor
    drops from 1.0 to 0.8. Run on five units since 2026-10-05.
    [calibration.yaml]
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2026-10-07 sd_spi_card: drop the f_getfree after mount; it reset units on a dirty card
    mount_card_() called f_getfree("0:") only to log the filesystem type. When the
    card's FSINFO free count is not valid, as after a power cut mid-write, FatFs
    scans the whole FAT over SPI, which on a large card runs past the 5 s task
    watchdog. That happens inside setup(): task_wdt on loopTask, SW_CPU_RESET, and a
    card left mid-transfer, so the next boot's mount fails with
    ESP_ERR_INVALID_RESPONSE until the periodic remount succeeds and crashes the
    unit again. Enough of those in a row land it in safe mode.
    Seen on f8:b3:b7:c6:64:60 on the calibration rig (backtrace through
    sd_spi_card.cpp:85, f_getfree, move_window, sdm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
    [sd_spi_card.cpp]
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
